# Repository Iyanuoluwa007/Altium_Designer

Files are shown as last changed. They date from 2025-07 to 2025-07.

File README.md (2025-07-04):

# Embedded Control System for an Autonomous Cleaning Robot

This repository documents the design and implementation of the **electronic control system** for an autonomous cleaning robot. It includes detailed PCB and schematic designs created using **Altium Designer**, covering four main subsystems: Power Supply Unit (PSU), USB Control Unit (UCU), Microcontroller Unit (MCU), and Motor Driver Unit (MDU).

## 📌 Project Overview

The objective was to create a robust, modular embedded control system capable of powering and managing key robotic functions such as:

- Obstacle detection and avoidance  
- Motor control and path navigation  
- Wireless communication via ESP32  
- Integration with peripherals like cameras, ultrasonic sensors, and LCDs  

## 🔧 Hardware Components

- **PSU:** Based on LM2596T-5.0 and LM2596T-3.3 for 5V and 3.3V outputs  
- **UCU:** FT232RL-based USB-to-Serial interface  
- **MCU:** ATmega128 microcontroller interfacing with sensors and wireless modules  
- **MDU:** L6205 dual full-bridge motor driver for bidirectional DC motor control  
- **PCB Tool:** Altium Designer (schematic, layout, DRC, and 3D visualization)

## ✅ Features

- Power-efficient voltage regulation with thermal management
- Fault-protected motor driver system
- Multiplexed UART switching for optimized communication
- Altium DRC-verified PCB designs with ground polygon pour
- Modular design enabling system scalability

## 📷 Previews

| Schematic | PCB Layout | 3D Render |
|---|---|---|
| PSU, UCU, MCU, MDU | 2D Altium Layout | Full-board 3D View |

> Note: Visuals available in the `3d_views/` and `outputs/` folders.

## 🔬 Testing & Validation

- **DRC:** No critical violations (Silk-to-solder mask clearance warning only)
- **Thermal Analysis:** Optimized using hatched polygon pour
- **System Integration:** Verified functional with all sensors and modules

## 📡 Future Improvements

- Add heatsinks/fans for thermal management  
- Upgrade to brushless DC motors  
- Include current sensing for real-time diagnostics  
- Add supercapacitor-based backup power

## 📚 References

Key component datasheets and academic papers are cited in the full [project report](./docs/Oke_Iyanuoluwa_Mech_Report.pdf).

## 👥 Author

- **Oke Iyanuoluwa Enoch**

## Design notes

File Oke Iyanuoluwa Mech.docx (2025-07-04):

Design and Implementation of the Embedded Control System for an Autonomous Cleaning Robot

Oke Iyanuoluwa Enoch

Team members: Love Akinrele, Ifeorah Anthony, Revanth Reddy

@00659936

Lecturer: Dr Theo Theodoridis

Module Title: Mechatronics

Programme: MScs. Robotics and Automation

School of CSE, University of Salford, Manchester M5 4WT, UK

i.e.oke@edu.salford.ac.uk

Abstract - This report details the design and implementation of the control system for an autonomous cleaning robot. The project covers the design and development of key electronic subsystems, including a Power Supply Unit (PSU), USB Control Unit (UCU), Micro-Controller Unit (MCU), and Motor Driver Unit (MDU). Using Altium Designer Software for schematic designs and PCB layout were created for each subsystem. The design adheres to professional standards, ensuring efficient operation and integration of sensors and actuators. Performance tests demonstrate the robustness of the system, providing a reliable foundation for further development in robotic cleaning applications.

I. Introduction

The rapid growth in demand for automation in both household and industrial cleaning tasks has significantly advanced robotic technologies. Robots' ability to perform repetitive, labor-intensive tasks autonomously and efficiently has made them indispensable in these environments. This report focuses on the design and implementation of the electronic control system for an embedded cleaning robot, which integrates key components such as motor drivers, sensors, and power management units. These components form the foundation of the robot’s functionality, enabling it to navigate, clean, and avoid obstacles effectively.

The motivation behind this investigation lies in the challenge of developing a cost-effective, reliable, and efficient cleaning robot capable of operating in diverse environments. The growing adoption of smart home and industrial automation solutions inspired this project, as these technologies aim to enhance productivity and streamline routine tasks. The primary objective of this study is to design an electronic control system that optimally manages the robot’s operations, from basic movement and cleaning behaviors to advanced obstacle detection and avoidance.

This investigation is particularly important for advancing the field of embedded robotic systems. Improvements in control systems, such as optimized motor drivers and power management, can significantly enhance the performance, efficiency, and adaptability of autonomous robots. Additionally, the integration of advanced control algorithms into the system contributes to the development of more sophisticated and capable robotic platforms. The system developed in this project lays the groundwork for future innovations in autonomous cleaning robots, providing a scalable solution that can be further refined for broader applications.

Throughout this project, collaborating with students from Pakistan and Nigeria emphasized the significance of fostering an inclusive and supportive environment. Each team member brought a unique cultural, ethnic, and educational perspective, so we prioritized open communication and mutual respect. We actively encouraged the sharing of diverse viewpoints during brainstorming sessions and problem-solving discussions, which enriched our project by providing fresh insights into design challenges.

We recognized the importance of accommodating religious and cultural differences by remaining flexible with meeting times to respect prayer schedules and personal commitments. Additionally, we were mindful of varying educational backgrounds, ensuring that technical concepts were openly discussed so everyone felt supported in understanding and contributing to the project's technical aspects.

By cultivating a culture of respect, inclusion, and cooperation, we enhanced both teamwork and creativity. This inclusive approach allowed us to collaborate harmoniously, providing equal opportunities for every member to contribute. Ultimately, this not only improved the quality of our work but also led to the overall success of the project, showcasing the value of diversity in achieving shared goals.

The remainder of this report is organized as follows. The Literature Review section examines current research and technological advancements related to embedded cleaning robots. The Methods section provides an in-depth description of the electronic subsystems' design, including Power Supply Unit, USB Control Unit, Micro-Controller Unit, and Motor Driver Unit. In the Results section, experimental outcomes and performance evaluations are presented. Finally, the Conclusions section discusses the findings and potential directions for future work.

This report focuses solely on the electronic design aspect of the project, while programming and mechanical design are covered in team members' reports, collectively providing comprehensive documentation of the embedded control system for an autonomous cleaning robot.

II. Literature Review

The growing demand for autonomous cleaning solutions in households and industries has driven research in robotic control systems, sensor integration, and power management. This review explores key technologies in embedded cleaning robots, focusing on control units, motor drivers, and energy systems. It highlights areas for innovation and advancements in control algorithms to enhance performance and reliability.

The author [3] presents the development of a vacuum cleaner robot aimed at automating household cleaning. The robot is designed with an Arduino-based control system, utilizing ultrasonic sensors for navigation and obstacle detection. It features a disk-shaped body, two rear wheels, and a front caster for maneuverability, with rotating sweepers to gather dirt into a vacuum. Powered by lithium-ion batteries, it operates for two hours on a full charge. The study demonstrates the robot’s efficiency in cleaning and navigating, though limitations such as the dustbin size and navigation glitches were noted. Future improvements could involve scaling up the dustbin and enhancing navigation systems for broader applications in home and office environments.

The authors [4] present the development of an autonomous robotic vacuum cleaner designed to save time and reduce effort for users. The system employs multiple sensors, such as infrared (IR) and ultrasonic sensors, for obstacle detection and navigation. A central ARM Cortex M3 controller processes sensor data and controls the robot's movement via permanent magnet DC (PMDC) and servo motors. The vacuum cleaner operates autonomously, utilizing suction to collect dirt. The robot is designed to assist busy individuals, the elderly, and physically challenged users. With future advancements, the robot has potential applications in homes, offices, and other public spaces.

The authors [5] present the development of a smart vacuum cleaner designed to operate autonomously without human intervention. The system integrates an RC car carrying a vacuum cleaner, controlled via an Arduino UNO microcontroller. An ultrasonic sensor detects obstacles, guiding the car to adjust its path based on obstacle distance. A CPU fan provides suction, collecting dust into a detachable container. The cleaner is powered by batteries, making it portable and efficient. The system offers a cost-effective and straightforward design, with potential applications in hazardous environments and daily cleaning tasks. Future improvements may include enhanced dust collection mechanisms and further automation.

The authors [6] present a Bluetooth-based smart vacuum cleaner designed for autonomous cleaning using IoT technology. The system includes a vacuum mounted on a mobile robot chassis equipped with sensors, a microcontroller, and Bluetooth communication. Controlled via a mobile app, the vacuum cleaner can navigate around obstacles and perform tasks remotely. The system uses sensors to detect its environment and an RFID-based positioning system for accurate location tracking. The robot autonomously cleans predefined areas and self-charges when needed. The study demonstrates that the integration of IoT and open-source hardware can facilitate daily household tasks, providing a functional and cost-effective solution for smart cleaning.

The authors [7] designed and implemented a low-cost vacuum cleaner robot controlled via a smartphone, aimed at being accessible to more users. The robot autonomously navigates around obstacles using ultrasonic and infrared sensors while being controllable through a mobile application. It integrates basic cleaning algorithms such as random walk and snake movement to clean efficiently, avoiding walls and cliffs. The study highlights the robot’s ability to provide efficient, low-power cleaning with cost-effective components, demonstrating that affordable robotic solutions for household chores are viable.

The authors [8] present the design and development of a prototype robot vacuum cleaner, using low-cost, off-the-shelf components. The navigation system employs fuzzy logic to enable efficient movement in unknown environments. The hardware includes a Rex-12 Round Robot Base and SRF08 ultrasonic sensors, while the software relies on eLinOS and Simulink for control and navigation. The system was validated using Software-in-the-Loop (SIL) simulations and a virtual prototype to test the navigation algorithm. However, experimental tests revealed the need for improvements in the sensing system to enhance position estimation accuracy.

The authors [9] designed a dual-mode robot vacuum cleaner prototype based on Arduino Uno, which operates in both automatic and manual modes. The robot uses a Sharp GP proximity sensor for obstacle detection and a Bluetooth HC-05 module for smartphone control. In automatic mode, the robot navigates randomly, avoiding obstacles, while in manual mode, users control the robot via a smartphone app. The prototype was tested for suction efficiency and maneuverability, showing limitations in steep slopes and larger debris handling. Further improvements are recommended for enhanced performance.

The authors [10] developed a wireless charging system for robot vacuum cleaners using inductive power transfer (IPT) technology. The system employs curved coils and passive power repeaters to enhance magnetic field coupling, improving charging efficiency despite coil misalignment. The prototype, tested with a 32W power transfer capacity at 100 kHz, demonstrated successful charging under simulated conditions. However, the system showed some limitations in power transfer optimization, suggesting future improvements in coil design and the potential use of active power repeaters for greater efficiency.

The authors [11] developed an Arduino-based smart vacuum cleaner robot, designed to clean autonomously without human intervention. The robot uses an Arduino Uno, ultrasonic sensors for obstacle detection, and motor shields to control movement. Powered by a 12V battery, the vacuum system includes a fan and motor for suction, effectively cleaning hazardous environments. The robot was tested for its obstacle avoidance and cleaning capabilities. While cost-effective and customizable, limitations were noted in efficiency when handling uneven surfaces, and further improvements were suggested for enhanced performance.

The author [12] discusses the design of a vacuum cleaner motor drive inverter using the EPC9176 evaluation board. The inverter uses three EPC23102 eGaN ICs in a three-phase configuration, providing high efficiency and power density. It operates at switching frequencies up to 250 kHz and delivers 18 ARMS with a heatsink. The design incorporates protection functions, current and temperature sensing, and a microcontroller interface. The system is optimized for BLDC motor control, demonstrating reduced torque oscillations, improved efficiency, and better current waveforms for vacuum cleaner applications

The authors [13] designed and analyzed an automatic robotic vacuum cleaner using an Arduino microcontroller and axial fan. The robot uses ultrasonic sensors for obstacle detection and a motor-driven wheel system for movement. Powered by a 12V rechargeable Li-Po battery, it runs for 20-30 minutes on a full charge. Simulation was performed using Coppelia Robotics and ANSYS Fluent to analyze vacuum efficiency. The design is affordable and suitable for Indian markets, with potential applications in households and industries.

The authors [14] designed and fabricated a robotic vacuum cleaner with autonomous functionality using an Arduino Uno and various sensors. The robot features a vacuum system, mopping mechanism, and drying capability, supported by 12V motors for movement. It integrates IR and ultrasonic sensors for obstacle detection and navigation. The control system allows the robot to switch between various cleaning modes and adjust its speed. The study highlights the potential of this cost-effective design for domestic use, especially for elderly or busy individuals.

The authors [15] proposed the integration of Altium Designer software in teaching electronic circuits. The software provides a platform for schematic capture, simulation, and PCB design, allowing students to visualize and analyze circuits effectively. It simplifies debugging and error correction while offering features like fourier analysis, waveform simulation, and cross-probing. The study demonstrates how Altium Designer enhances students' learning experience by reducing manual tasks, improving accuracy, and offering hands-on circuit design, making it an essential tool for both education and research.

The authors [16] developed an autonomous robotic vacuum cleaner that operates in three modes: manual, automatic, and timer-based. The device integrates a NodeMCU microcontroller and ultrasonic sensors for obstacle detection, along with a vacuum and wet mopping mechanism. Controlled via a smartphone app, the robot can clean surfaces by avoiding obstacles and adjusting its path accordingly. It features both vacuuming and wet mopping capabilities for comprehensive cleaning. Testing demonstrated successful obstacle avoidance and efficient cleaning, though the authors suggest further refinement for wider applications.

The authors [17] proposed a cost-effective IoT-based vacuum and mopping robot designed with an Arduino Uno board, ultrasonic and infrared sensors, and Bluetooth control. The robot operates in both automatic and Bluetooth-controlled modes, utilizing a vacuum kit for dust collection and side brushes for efficient cleaning. Ultrasonic sensors detect obstacles, while an L293D motor driver controls the robot's movement. The design aims for maximum cleaning coverage and mobility. Testing showed efficient cleaning and obstacle avoidance, with potential for further enhancements in sensor accuracy and functionality.

The authors [18] developed a robot vacuum cleaner using the Arduino Mega 2560 microcontroller, incorporating ultrasonic sensors for obstacle detection and dust sensors for cleaning. The robot uses four ultrasonic sensors to navigate in cardinal directions and detects dust levels below 0.30 mg/mm³ to activate cleaning. The vacuum operates in forward, backward, and turning movements based on sensor input. The system's performance is displayed on an LCD, with the robot stopping if thicker dust or obstacles are detected. Testing confirmed effective movement and cleaning within the specified parameters.

The authors [19] designed an autonomous vacuum cleaning robot with a focus on cost optimization. The robot features an Arduino Mega 2560 microcontroller, limit switches, infrared sensors, and a DC motor to control movement and obstacle avoidance. A bevel gear system reduces the need for individual motors for each cleaning brush. The robot is designed to vacuum dust and small debris efficiently while navigating obstacles and stairs. With a low manufacturing cost of ₹5,410, the prototype performs well for commercial cleaning but could benefit from additional features such as GPS and automatic charging systems.

The authors [20] developed an intelligent vacuum cleaner that integrates sensor, positioning, and control technologies for autonomous cleaning. The system features an Stc89c52rc microcontroller, infrared sensors for tracking and obstacle avoidance, and ultrasonic sensors for distance detection. The vacuum cleaner can navigate, avoid obstacles, and clean efficiently without manual control. It also includes a motor control circuit for dust collection and a remote control for user interaction. The design emphasizes intelligence, efficiency, and ease of use, marking a significant advancement in household cleaning technology.

The authors [21] designed a smart vacuum cleaner equipped with indoor localization and obstacle detection. The robot uses TurtleBot technology with a SLAM algorithm for simultaneous mapping and localization. It features infrared and ultrasonic sensors for object detection, a motor driver system, and is controlled by an Arduino microcontroller. The vacuum can operate in both manual and autonomous modes. The study emphasizes the use of simulation environments like ROS and Gazebo to optimize path planning and improve cleaning efficiency, showcasing potential applications in homes and commercial spaces.

III. Methods

The intelligent system architecture of the Embedded Cleaning Robot integrates four core functions: rectangular path navigation, target tracking for recharging, obstacle avoidance, and random wandering to explore uncovered areas. Each function is managed by the robot's main control board, consisting of a Power Supply Unit, USB Control Unit, Micro-Controller Unit, and Motor Driver Unit, enabling efficient, adaptive operation in dynamic environments with seamless sensor integration and precise motor control.

Power Supply Unit (PSU)

The Power Supply Unit (PSU) uses two LM2596-based step-down regulators to convert a 12V input into two stable DC outputs:

5V Output: Using the LM2596T-5.0 regulator, this output powers components requiring 5V.

3.3V Output: Using the LM2596T-3.3 regulator, this output powers components requiring 3.3V.

These designs prioritize efficiency, stability, and thermal management, ensuring the proper functioning of embedded systems and other sensitive electronics. Below are the schematic and PCB layout designs for the PSU, prepared using Altium Designer, showing component placement and connections. This setup provides efficient power to the system with minimal ripple, high stability, and low thermal impact.

LM2596T-5.0:

Model Description

The PSU design features the LM2596T-5.0, a fixed-output buck converter that steps down a 12V input to 5V with minimal ripple and noise, supporting up to a 3A load. Operating at a fixed switching frequency of 52 kHz, it ensures compact and efficient filtering while incorporating fault protection mechanisms such as thermal shutdown and overcurrent limits.

Electrical Characteristics

The LM2596T-5.0 offers the following electrical parameters for the PSU:

- Output Voltage: Stable at 5V, with typical tolerances of ±4% across load and line conditions.

- Oscillator Frequency: Fixed at 52 kHz, which maintains switching frequency consistency and improves voltage regulation allowing compact and efficient filter designs.

- Current Limit: 5.8A peak, preventing excessive current flow and protecting against faults.

- Input Voltage Range: Operates with a wide range of input voltages.

Thermal Management and Power Dissipation

- Thermal Shutdown: Built-in thermal shutdown ensures safe operation by automatically disabling the IC if temperatures exceed safe limits.

- Thermal Resistance: With θJA at 65°C/W (TO-220 package) and junction temperature max at 125°C, the power dissipation under normal operation is within safe ranges with limited or no additional heat sink requirement.

- Power Dissipation Equation: Power dissipation (PD) can be calculated using:

PD=(VIN x IQ)+(VO/VIN) X ILOAD x VSAT

where VIN is 12V, IQ (quiescent current) is 5 mA, VO is 5V, and VSAT is approximately 1.4V for the LM2596T-5.0.

Performance Under Load and Temperature Tolerances

Graphs from the datasheet show:

- Efficiency vs Load Current: At 3A, efficiency reaches around 77%.

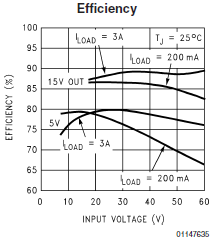
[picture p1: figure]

- Ripple Voltage: The output ripple can be managed with the 1000 µF output capacitor, achieving smooth operation and low noise at approximately 1% of the output voltage.

## ~~I~~mplementation Design

The LM2596T-5.0 PSU is designed to efficiently convert a 12V DC input to a stable 5V DC output, ideal for powering embedded systems.

i. Input Power and Filtering: The 12V input, provided through a power jack and SPST switch, is stabilized by capacitors (100 µF and 10 nF) to filter high-frequency noise, reducing oscillations for smooth regulator operation.

ii. Voltage Regulator Module: The LM2596T-5.0 regulator steps down the input to a steady 5V, chosen for its efficiency and ability to manage higher input voltages with minimal power loss.

iii. Inductor (100 µH): The 100 µH inductor supports energy storage and smooths the current, minimizing ripple crucial for stable applications.

iv. Output Capacitor (1000 µF): Positioned as the primary output filter, the 1000 µF capacitor smooths residual ripple, enhancing stability. Its voltage rating is selected above 5V to ensure durability against minor surges.

v. Catch Diode (1N5822): This Schottky diode, with fast switching and low forward voltage drop, prevents current backflow, protecting the circuit during off cycles.

vi. Indicator LED and Resistor: An LED and 330-ohm resistor signal the output status, providing a simple verification tool.

vii. Output Connector: A 2-pin connector offers easy 5V access for external devices, creating a reliable, efficient PSU for systems requiring stable power.

LM2596T-3.3:

Model Description

The LM2596T-3.3 regulator steps down a 12V input to a stable 3.3V output. It supports up to 3A load and includes the same thermal and overcurrent protection as the LM2596T-5.0.

Electrical Characteristics

- Output Voltage: Nominal output is 3.3V, with ±4% tolerance.
- Oscillator Frequency: Fixed at 52 kHz, enabling efficient filtering.
- Current Limit: Peak current limit of 5.8A.
- Input Voltage Range: Accepts input voltages of 12V in this PSU design.

Thermal Management and Power Dissipation

- Thermal Shutdown: Automatically disables the IC in case of overheating.
- Thermal Resistance: θJA: 65°C/W for the TO-220 package. Maximum junction temperature: 125°C.
- Power Dissipation: Calculated similarly to LM2596T-5.0, using:

PD=(VIN x IQ)+(VO/VIN) X ILOAD x VSAT

where VIN is 12V, IQ (quiescent current) is 5 mA, VO is 3.3V, and VSAT is approximately ~1.4V.

Performance Under Load and Ripple Voltage

- Efficiency: Efficiency can reach 78% under typical load conditions.
- Ripple Voltage: Ripple is minimized using a 330 µF output capacitor, maintaining noise at around 1% of output voltage.

Implementation Design

The LM2596T-3.3 PSU is designed to efficiently convert a 12V DC input to a stable 3.3V DC output, ideal for powering embedded systems.

i. Input Power and Filtering: The 12V input is filtered using a 330 µF capacitor to suppress high-frequency noise.

ii. Voltage Regulator Module: The LM2596T-3.3 steps down 12V to 3.3V, ensuring stability and low noise.

iii. Inductor: A 33 µH inductor smooths current flow, reducing ripple.

iv. Output Capacitor: A 330 µF capacitor filters the output voltage, ensuring a stable 3.3V output.

v. Catch Diode: A 1N5822 Schottky diode prevents reverse current flow.

vi. Indicator LED and Resistor: An LED and 330-ohm resistor signal the presence of the 3.3V output.

vii. Output Connector: A 2-pin connector provides access to the regulated 3.3V output.

Below is the Schematic and PCB diagram showing the connection of the Power Supply Unit (PSU):

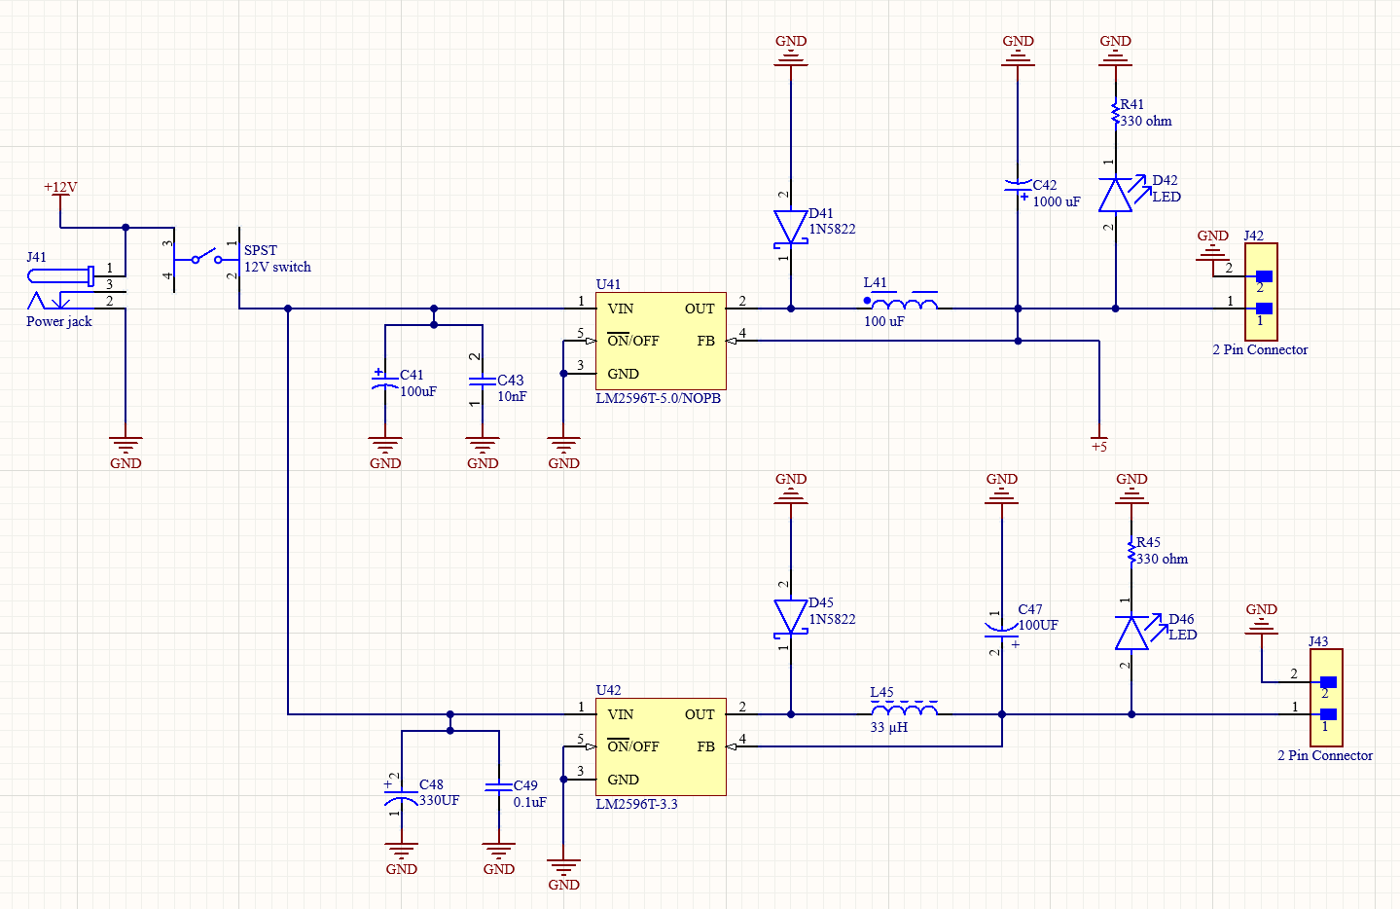
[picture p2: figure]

Fig. 1a The schematic diagram of the PSU (Power Supply Unit

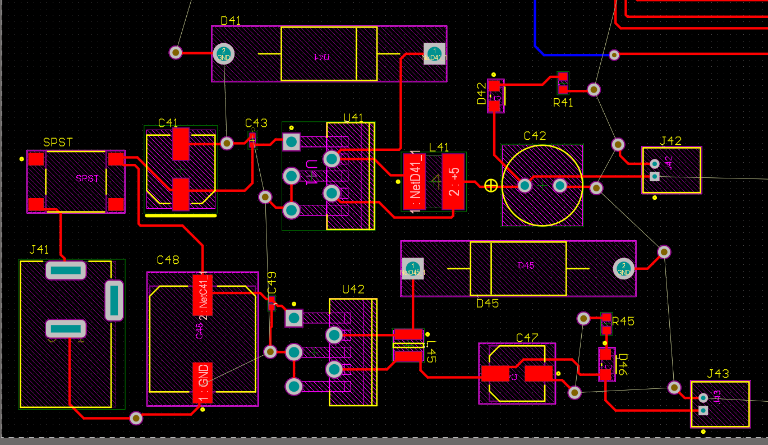
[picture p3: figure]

Fig 1b. The Printed Circuit Board (PCB) of the PSU (Power Supply Unit

USB Control Unit (UCU)

The UCU is the USB interface used to establish bidirectional communication with the PC over a USB-to-Serial protocol. Using the FT232RL functions as the USB-to-serial UART interface. The design can include the following essential elements:

- VCCIO: Configured based on the voltage requirement (1.8V to 5.25V). This can be set to interface with other components in the circuit.

- USB Data Lines (USBDP and USBDM): Connected to the USB connector with internal pull-up resistors for proper USB 2.0 full-speed communication.

- CBUS Pins: Configurable GPIO pins (CBUS0-4) set in the EEPROM to control additional functions like LEDs for data indication or to manage power settings via PWREN.

FT232RL Configuration and Analysis

The FT232RL integrates critical functions needed for USB communication and UART interfacing:

Electrical Characteristics:

- Operating Voltage: 3.3V to 5V nominal operating voltage; the internal LDO provides a regulated 3.3V output.

- Current Requirements: Operating at approximately 15mA in normal mode and 70µA in USB suspend mode, supporting low-power applications.

Thermal Characteristics:

- Suitable for a temperature range of -40°C to 85°C, making it versatile for embedded applications.

- The IC includes an internal power-on-reset (POR) and a 3.3V LDO, reducing the need for additional thermal management components like heat sinks for moderate power applications.

Performance Specifications:

- Data Rate: Capable of up to 3 Mbaud for serial communication, with a baud rate generator allowing non-standard rates via internal prescaler adjustments.

- Integrated EEPROM: Stores device descriptors, VID, PID, and custom configurations for the CBUS pins(FT232R).

FT232RL Key Functional:

- USB Protocol Engine: Manages USB control endpoint data flow and low-level protocol requests from the host.

- UART Controller: Converts data between USB and UART formats, with support for signal inversion and a configurable drive strength to interface efficiently with various UART levels.

The baud rate equation for the FT232RL is calculated using:

Baud Rate = 3,000,000 / n + x

where n is an integer between 2 to 16,384 and x a fractional divisor (0, 0.125, etc.), giving a wide range of achievable baud rates from 183.1 baud to 3,000,000 baud.

## Implementation Design

The FT232RL chip serves as the primary USB interface in the USB Control Unit (UCU), facilitating bidirectional data communication between a PC and an embedded system by converting USB signals to UART protocol.

1. USB Data Lines (USBDP, USBDM): The differential data lines, D+ (USBDP) and D- (USBDM), are directly connected to the USB port. These lines manage data transmission to and from the PC, enabling communication via USB.

2. Power Supply (VCCIO): VCCIO pin supplies the logic level for UART and CBUS pins, configured to either 3.3V or 5V depending on the MCU’s interfacing requirements. This ensures the chip communicates at the proper voltage level.

3. UART Interface Pins (TXD, RXD): The TXD (Transmit) and RXD (Receive) pins handle serial data exchange with the ATmega128-16AU, providing full-duplex communication capability.

4. CBUS I/O Pins (CBUS0-4): Configurable through the integrated EEPROM, CBUS pins can be assigned to auxiliary functions like TX and RX LED indicators or used as general-purpose I/O pins.

5. EEPROM: The FT232RL’s internal EEPROM holds USB descriptors (e.g., Vendor ID and Product ID) and the configuration settings for CBUS pins, allowing easy customization and integration with USB host systems.

6. PCB Layout and Design Considerations:

- USB and Power Routing: The D+ and D- lines are routed as differential pairs with controlled impedance to maintain signal integrity. Power traces are designed short and wide to handle current demands efficiently.

- LED Indicator Circuit: LEDs, each with a 330-ohm resistor (R33 for RX, R34 for TX), indicate the operational status of data transmission, providing a visual check for communication activity.

- The VBUS signal is directly connected to 2OE (Pin 4) of the multiplexer (Z2).

7. Connector Configuration:

- USB Connector: The USB-B connector interfaces with the PC, allowing standard USB connectivity.

Below is the Schematic and PCB diagram showing the connection of the USB Control Unit (UCU):

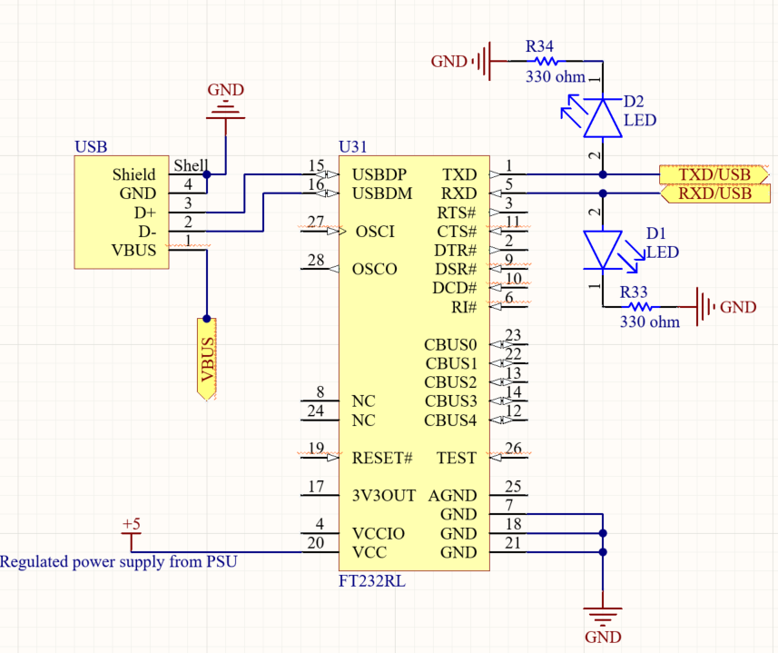
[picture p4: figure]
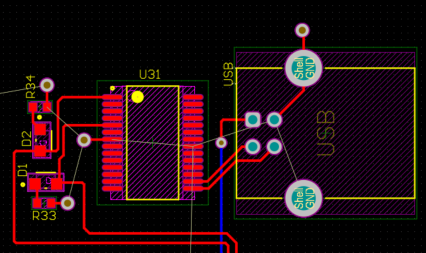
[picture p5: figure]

Fig. 2a The schematic diagram of the USB Control Unit (UCU)

Fig. 2b The Printed Circuit Board (PCB) of the USB Control Unit (UCU)

Motor Driver Unit (MDU)

The Motor Driver Unit (MDU) uses the L6205 full-bridge motor driver IC, designed for driving DC motors efficiently while ensuring reliability and robust protection. The L6205 supports a dual full-bridge configuration, making it ideal for driving two independent DC motors. With built-in features like overcurrent protection, thermal shutdown, and undervoltage lockout, the MDU ensures safe and stable operation for embedded motor control systems.

Features of the MDU

- Dual Full-Bridge Motor Driver: Supports two independent motors with separate control signals.
- High Voltage and Current Capability:

i. Supply Voltage (VSA/VSB): Up to 52V.

ii. Output Current (IOUT): 2.8A RMS per channel.

- Integrated Protection Mechanisms:

i. Overcurrent Protection: Prevents damage due to motor stall or excessive load.

ii. Thermal Shutdown: Disables operation when IC temperature exceeds the threshold.

iii. Undervoltage Lockout: Ensures the motor operates only within safe voltage levels.

- Low RDS(on): MOSFET switches integrated into the driver reduce heat dissipation.

Circuit Implementation and Connections

The MDU design consists of two identical motor driver circuits, each built around an L6205 IC. The following sections describe the critical components and their functions:

1. Input Power Supply

i. Voltage Source (VS): The motors are powered by a 12V DC input.

ii. Capacitors (C13, C14, C15, C16):

- 100 µF capacitors filter noise and smooth voltage input.

- 220 nF bootstrap capacitor (CBOOT): Ensures high-side MOSFETs can switch correctly.

2. Control and Logic Inputs

i. Enable Pins (EN_A, EN_B): Used to enable or disable each motor. Controlled by microcontroller logic.

ii. Input Pins (IN1, IN2): Determine the motor's rotation direction based on logic levels:

- IN1 High, IN2 Low: Forward rotation.

- IN1 Low, IN2 High: Reverse rotation.

- Both Low: Motor brakes.

iii. Resistors (M_RENA,B and M_CENA,B): Pull-up and pull-down resistors stabilize input signals, minimizing noise.

3. Output Stage

i. The driver outputs (OUT1a, OUT2a, OUT1b, OUT2b) connect to the motor terminals via a 2-pin connector (J4, J5).

ii. Each channel provides a full-bridge output, allowing bidirectional control of motors.

4. Bootstrap Circuit

Diodes (1N4148): Fast recovery diodes ensure proper charging of the bootstrap capacitors during switching cycles.

5. Sensing and Protection

Sense Resistors (SENSE_A, SENSE_B): Connect to the ground for overcurrent sensing. These are crucial for triggering protective mechanisms within the IC.

Thermal Management and Power Dissipation

i. Thermal Shutdown: The L6205 has an internal thermal sensor that disables operation when the junction temperature exceeds safe limits.

ii. Power Dissipation (PD): Power dissipation for each channel can be calculated using:

PD = I² × RDS (on) × Duty Cycle

With the low RDS (on) value of the L6205, power loss is minimal, enhancing efficiency and reducing the need for large heat sinks.

Performance Characteristics

- Efficiency: The low RDS(on) and optimized switching characteristics result in high efficiency across various loads.
- Current Control: Peak current control prevents overheating or motor damage during stall conditions.
- Motor Speed Control: Achieved through Pulse Width Modulation (PWM) applied to the enable pins, allowing smooth speed variations.

Implementation Benefits

The MDU, designed with the L6205 IC, provides the following advantages:

i. Compact Design: Integration of MOSFETs and protection features reduces the need for external components.
ii. High Reliability: Built-in protections ensure long-term stability, even under demanding conditions.
iii. Easy Integration: Compatibility with standard microcontrollers simplifies control logic implementation.

Below is the Schematic and PCB diagram showing the connection of the Motor Driver Unit (MDU):

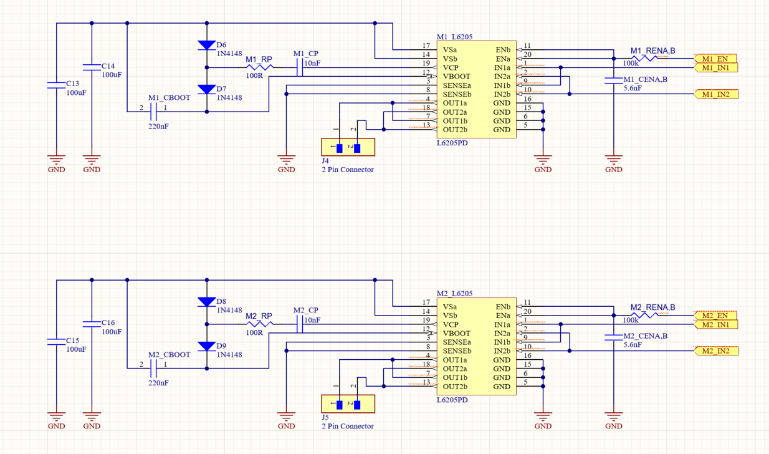
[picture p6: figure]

Fig. 3a The schematic diagram of the Motor Driver Unit (MDU)

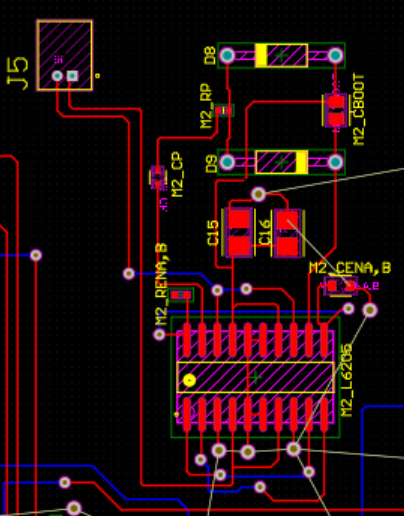
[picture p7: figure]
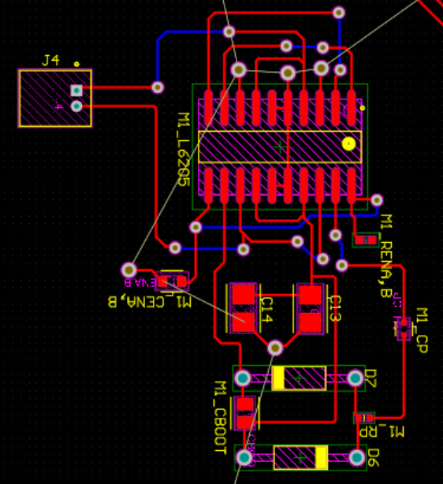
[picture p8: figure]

Fig. 3b The Printed Circuit Board (PCB) of the Motor Driver Unit (MDU)

Microcontroller Unit (MCU)

Micro-Controller Unit (MCU): The MCU is based on the ATmega128, a versatile and widely-used microcontroller from Atmel’s AVR family, known for its high performance and efficient power consumption. It operates on the Harvard architecture with a RISC-based instruction set, enabling efficient execution of embedded applications.

- Core Functionality: The ATmega128 serves as the central processing unit for the system, executing the programmed instructions to control connected sensors, peripherals, and communication modules.

- Integration with Peripherals: As evident in the provided schematic, the MCU interfaces with various components such as Ultrasonic sensors (CON1), a RPLidar (CON2), a Camera (CON3), an I2C LCD (CON4), and an ADC (CON5). These connections highlight the MCU's ability to manage multiple inputs and outputs effectively.

Key Features of the ATmega128 in This Design

1. High Pin Count and I/O Flexibility:

The ATmega128 features 53 programmable I/O lines, enabling connectivity with a wide range of devices. For example, in the schematic:

- PORTB, PORTC, and PORTD are used for communication with peripherals like the ultrasonic sensor and camera module.

- PORTF is leveraged for ADC operations, allowing analog signals to be processed digitally.

2. Communication Protocols:

The microcontroller supports several communication protocols, such as SPI, I2C, and USART:

i. SPI communication is used for high-speed data exchange such as with the OV2640 camera module.

ii. I2C is used to connect the I2C-based LCD for efficient data transfer with minimal pin usage.

iii. USART facilitates communication with the ESP32-WROOM-32D module for wireless data exchange.

To ensure proper functionality, careful pin management has been implemented. For instance, the PB1/SCK line is shared between the ISP header and the camera module, with programming only possible when the camera is inactive.

3. Analog and Digital Conversions:

Equipped with a 10-bit ADC (on PORTF pins), the ATmega128 can convert analog signals from sensors into digital data for processing.

4. Timers and PWM:

The ATmega128 includes four timers (8-bit and 16-bit) to handle tasks like event counting, signal generation, and control. PWM outputs are also used for applications requiring precise modulation, such as motor control.

5. Programming and Debugging:

An In-System Programming (ISP) header is connected to PB1-SCK, PB2-MISO, PB3-MOSI, and the RESET pin, enabling programming and debugging of the microcontroller during development.

6. Crystal Oscillator:

The design includes a 16 MHz crystal oscillator with 18 pF capacitors (C5 and C6), providing the clock signal necessary for stable MCU operation.

Detailed Component Connections

1.Power Supply Connections:

- The ATmega128 is powered by a stable 5V supply regulated by the LM2596T-5.0.

- AVCC powers the ADC module, and AREF sets the reference voltage for analog-to-digital conversions.

- Decoupling capacitors stabilize the power supply and filter noise for reliable operation.

2. Clock Signal:

A 16 MHz external crystal oscillator provides the clock source for the MCU, ensuring precise timing and synchronization of internal processes.

3. Peripheral Connections:

- Ultrasonic Sensor (CON1):

Connected to PORTD (PD0-PD7) for transmitting trigger signals and receiving echo pulses for distance measurement.

- Camera Module (CON3):

The OV2640 camera module is linked to PORTC (PC0-PC7) for transferring image data to the MCU. SPI is used for communication.

- LCD Module (CON4):

An I2C-based LCD is connected via SCL and SDA pins on PORTC, enabling simple and efficient data display.

- ADC Inputs (CON5):

Analog sensors are connected to PORTF (PF0-PF7) for conversion of analog signals to digital data.

4. Wireless Communication Module (ESP32-WROOM-32D):

The MCU communicates with the ESP32 module via the USART interface on PD0 (TXD) and PD1 (RXD), enabling wireless communication over Wi-Fi.

5. Multiplexer:

The design utilizes two multiplexers (Z1 and Z2) for UART switching on the ATmega128.

Z1 connects CON2 (RPLidar) and the ISP to UART1 (PD2/PD3), controlled by the RESET signal. When RESET is HIGH, the ISP connects to UART1; when LOW, RPLidar is active.

Z2 handles UART0 (PE0/PE1), switching between the ESP32 and USB (FT232RL), controlled by the USB’s VBUS signal. When VBUS is HIGH, USB is active; when LOW, the ESP32 is connected. Pull-down resistors ensure stable signal transitions. This configuration enables automatic peripheral switching, optimizing UART usage without manual intervention.

6. ISP Programming Header (CON6):

Provides access to SPI pins (PB1-SCK, PB2-MISO, PB3-MOSI) and the RESET line for programming and debugging.

7. Status Indicator:

A status LED is connected to one of the I/O pins through a resistor, offering visual feedback about the system's operational status.

Below is the Schematic and PCB diagram showing the connection of the Motor Driver Unit (MDU):

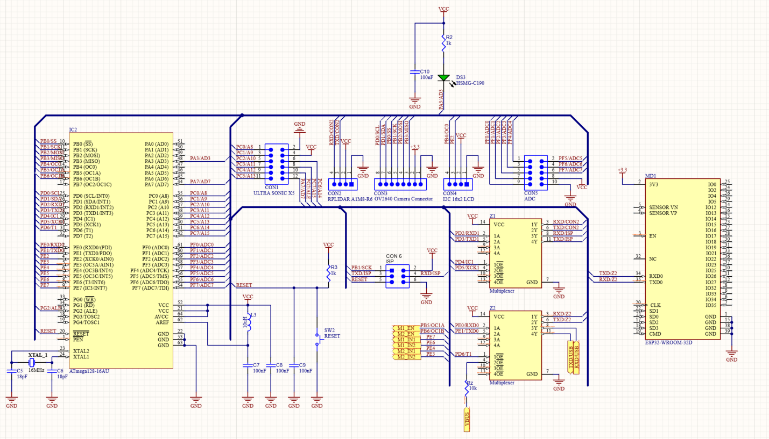
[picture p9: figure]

Fig. 4a The schematic diagram of the Microcontroller Unit (MCU)

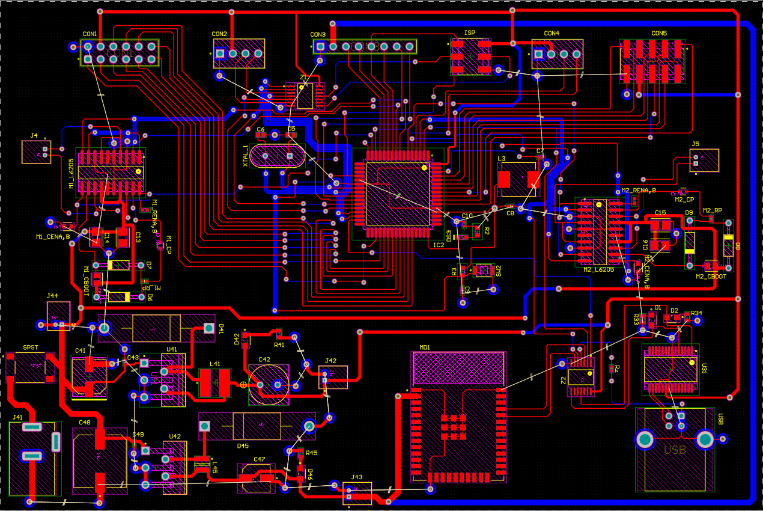
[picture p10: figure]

Fig. 4b The Printed Circuit Board (PCB) of the whole connection to the Microcontroller Unit (MCU)

IV. Results/ Experiments:

This section presents the outcomes and insights derived from the design and implementation of the embedded control system for an autonomous cleaning robot. Utilizing Altium Designer’s Design Rule Check (DRC), the schematic and PCB designs for critical subsystems were meticulously developed and rigorously validated. These results are supported by detailed analyses, 3D renderings, and rule-checking to ensure compliance with professional and industry standards.

The DRC was performed based on the following rule categories:

- Electrical
- Routing
- Surface-Mount Technology (SMT)
- Manufacturing
- High-Speed Design
- Placement

Upon executing the DRC, the Verification Report indicated that all circuit connections were correctly established with zero warnings. The only rule violation identified was related to the Silk to Solder Mask clearance.

The Silk to Solder Mask rule pertains to the required spacing between the silkscreen layer and the solder mask layer on the PCB. The identified violation occurred because the clearance did not meet the 10-mil threshold between the silkscreen and pad areas. This issue arises from the specific components and their placement on the PCB, as their designs do not fully conform to Altium’s default design rules. However, the violation does not compromise the general electrical functionality of the circuit and can therefore be safely disregarded in this context. The Altium Designer Design Rule Verification Report can be found in the link in the Appendices section below.

After performing the DRC, the PCB was properly grounded using the Polygon Pour. The Polygon Pour is referred to as the large area on a printed circuit board (PCB) that is filled with copper. It is often used for grounding, power distribution, or thermal management.

The polygon pours are typically categorized into: Solid and Hatched.

Solid Pour: A solid pour fills the entire defined area with a continuous layer of copper.

Hatched pour: It uses a grid or mesh-like pattern of copper to fill the area, leaving spaces between the copper lines.

In this design, a hatched polygon pour is applied to the bottom layer to connect all components to the ground (GND) net. The hatched pour effectively serves two critical functions:

- Heat Dissipation: The hatched pattern aids in spreading heat generated by components, minimizing the risk of overheating.

- Cost Efficiency: By reducing the amount of copper used compared to a solid pour, the design maintains cost-effectiveness while fulfilling thermal and grounding requirements.

The hatched pour ensures mechanical flexibility, making it suitable for applications where stress and bending may occur. This approach reflects a balanced consideration of performance, cost, and reliability.

Below show the full PCB circuit below:

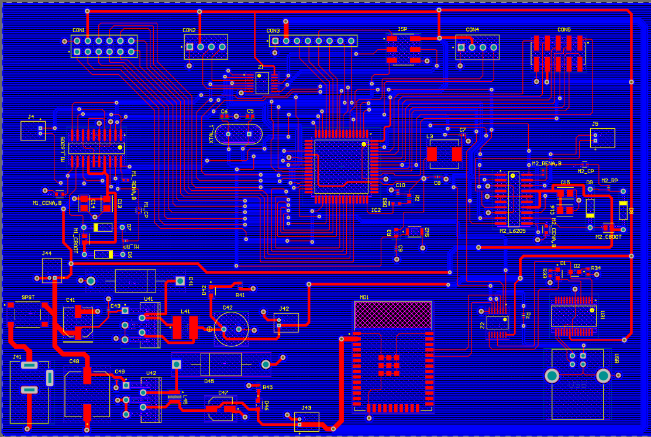
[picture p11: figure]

Fig. 5a 2d PCB Layout mode

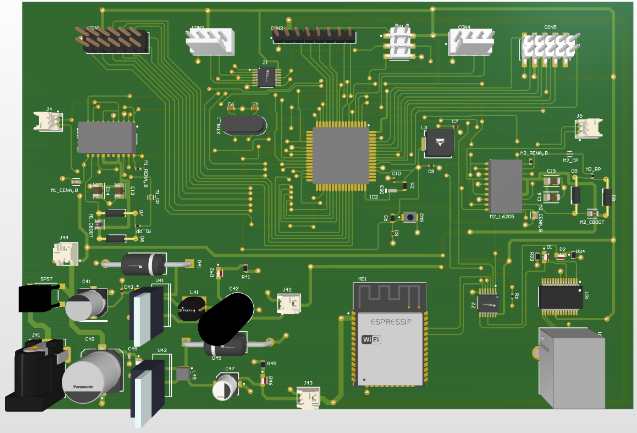
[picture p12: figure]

Fig. 5b 3d PCB Layout mode

V. Conclusions

This project successfully developed a robust electronic control system for an autonomous cleaning robot, integrating a Power Supply Unit (PSU), USB Control Unit (UCU), Microcontroller Unit (MCU), and Motor Driver Unit (MDU). This design adheres to professional and industry standards using Altium Designer for schematic and PCB layout development. The key results highlight:

- Efficient Power Management: The PSU efficiently converts a 12V input to stable 5V and 3.3V outputs, ensuring minimal ripple and optimized thermal management.
- Reliable Control System: The MCU based architecture effectively will manage the robot's cleaning functions, including navigation, obstacle avoidance, and recharging.
- Motor Driver Optimization: The MDU, based on the L6205 IC, provides smooth, bidirectional motor control with integrated overcurrent and thermal protection.
- Seamless Communication: The UCU's USB-to-Serial interface facilitates efficient data exchange between the robot and external systems.

The experimental results validated the functionality of these subsystems, ensuring seamless integration for effective robot operation.

Contributions

The design introduces several innovations that enhance functionality and efficiency.

- Power Management Optimization: The PSU uses a hatched polygon pour for grounding, providing improved heat dissipation and cost-effective thermal management.

- Enhanced Motor Control: The L6205 IC optimizes motor driver performance, ensuring smooth, reliable operations under various conditions.

- Integration of Multiplexers: The multiplexers (Z1, Z2) dynamically manage UART interfaces, allowing seamless switching between devices like the ESP32, USB, and RPLidar. This reduces hardware complexity, simplifies microcontroller pin allocation, and enables simultaneous multi-device communication without manual reconfiguration.

- ESP32 for Wireless Connectivity: The ESP32 module facilitates remote operation and real-time monitoring via Wi-Fi. It gives room for support of IoT functionalities such as scheduling, cloud data storage, and voice assistant integration, offering a powerful, cost-effective connectivity solution.

These innovations emphasize modularity, adaptability, and efficiency, setting a new standard for robotic cleaning system design and enhancing user convenience.

Future Developments

To enhance the electronic control system of the autonomous cleaning robot, several advancements are proposed:

- Heat Dissipation: Integrating a small, energy-efficient cooling fan or heat sinks on the PSU and Motor Driver Unit will mitigate heat buildup, ensuring consistent thermal performance during prolonged use.

- Power Management: Adaptive power management, including dynamic voltage scaling, can optimize energy usage based on workload, while a backup power mechanism (e.g., supercapacitor) ensures reliability during power transitions.

- Motor Control: Adding current-sensing circuits for dynamic load adjustments and upgrading to brushless DC motors will increase energy efficiency and durability.

- Diagnostics: Real-time power monitoring and status indicators for key subsystems will simplify maintenance and improve user feedback.

These developments aim to enhance reliability, energy efficiency, and scalability for future applications.

Overall Impact

The project demonstrates how an efficient, scalable control system can enhance the functionality and reliability of autonomous cleaning robots, contributing significantly to the field of household and industrial automation.

References

[1] Wikipedia, "Robotic vacuum cleaner," Wikipedia, the free encyclopedia. https://en.wikipedia.org/wiki/Robotic_vacuum_cleaner (accessed Oct. 30, 2024).
[2] My Project Circuits, "Design and construction of a microcontroller-based robot vacuum floor cleaner," My Project Circuits, https://www.myprojectcircuits.com/materials/design-and-construction-of-a-microcontroller-based-robot-vacuum-floor-cleaner/ (accessed Oct. 30, 2024).
[3] Asafa, T. B., Afonja, T. M., Olaniyan, E. A., & Alade, H. O. (2018). Development of a vacuum cleaner robot. Alexandria Engineering Journal, 57(4), 2911–2920. https://doi.org/10.1016/j.aej.2018.07.005
[4] Sagar, P., Kumari, A., Sanyal, V., Choudhary, R., & Diwan, A. (2016). A Review Paper on Autonomous Robotic Vacuum Cleaner, 4(ISSN-2347-4890).
[5] M, M., T S, V., V, B., Rao, S., & P S, G. (2021). Smart vacuum cleaner. Global Transitions Proceedings, 2(2), 553–558. https://doi.org/10.1016/j.gltp.2021.08.051
[6] Güllü, A., & Çağlar, M. (2019). Bluetooth Based Smart Vacuum Design and Implementation. Bilge International Journal of Science and Technology Research, ISSN: 2651-401X. https://doi.org/10.30516/bilgesci.489785.
[7] Eren, A., & Doğan, H. (2022). Design and implementation of a cost effective vacuum cleaner robot. Turkish Journal of Engineering, 6(2), 166–177. https://doi.org/10.31127/tuje.830282
[8] Design of a Prototype Robot Vacuum Cleaner - From Virtual Prototyping to Real Development. (2006). Proceedings of the Third International Conference on Informatics in Control, Automation and Robotics, 461–468. https://doi.org/10.5220/0001201004610468
[9] Rahayu, E. S., Mardiono, & Azis, D. A. (2020). Design of vacuum cleaner dual mode robot prototype based on arduino uno with bluetooth and smartphone communication. 6.
[10] Li, A., Kacprzak, D., & Hu, A. P. (2022). Wireless Charger Design of Robot Vacuum Cleaners with Power Repeaters for High Compatibility. Journal of Electromagnetic Analysis and Applications, 14(05), 47–64. https://doi.org/10.4236/jemaa.2022.145005
[11] Kumar, K. S., Pavan, M., Karthikeyan, N. K., Lokesh, P. S. V., Sasidhar, K., & Haritha, T. (2023). Arduino Based Smart Vacuum Cleaner Robot. International Journal for Research in Applied Science and Engineering Technology, 11(3), 416–424. https://doi.org/10.22214/ijraset.2023.49430
[12] eGaN® TECHNOLOGY. (n.d.). How to Design a Vacuum Cleaner Motor Drive Inverter Using EPC9176 Evaluation Boards.
[13] Harish Bala, S., Prajith, K., Siddharth, B., & Prashanth, B. (2020). Design and Analysis of Automatic Robotic Vacuum Cleaner. International Journal of Advanced Research in Engineering and Technology (IJARET), 11(11), 728–736. https://doi.org/10.34218/IJARET.11.11.2020.069
[14] Kumar, P., Rajpurohit, P., Krishna, H., & Chauhan, S. (2020). Design And Fabrication of Robotic Vacuum Cleaner. 8(ISSN: 2320-28820), 3436.
[15] Beltran, A., Hiwatig, C., Laguna-Agustin, J., & Villanueva, M. (2014). Teaching Electronic Circuits Using Altium Designer Teaching Electronic Circuits Using Altium Designer.
[16] Patil, S., Yelmar, S., Yedekar, S., Mhatre, S., & Pawashe, V. (2021). Autonomous Robotic Vacuum Cleaner Autonomous Robotic Vacuum Cleaner. International Research Journal of Innovations in Engineering and Technology (IRJIET), 5(4), 142–146. https://doi.org/10.47001/IRJIET/2021.504021
[17] Sridhar, S., Himabindu, R., Kumar, P., & Vasu, R. (2018). Design of IOT Based Vacuum Cleaning and Mopping Robot. 5.
[18] Rapa, C. I., Dephtios, E., Mariangga, C., & Patiung, N. (2022). A Design And Build A Robot Vacuum Cleaner. Journal of Physics: Conference Series, 2394(1), 012024. https://doi.org/10.1088/1742-6596/2394/1/012024
[19] Modi, J., & Siddhpuriya, N. (2021). Manufacturing of Autonomous Vacuum Cleaning Robot with Optimum Cost Manufacturing of Autonomous Vacuum Cleaning Robot with Optimum Cost. International Journal of Advance Research in Engineering, 8(6), 2394–2444.
[20] Liu, Y., Rong, X., & Bu, S. (n.d.). Design of Intelligent Vacuum Cleaner.
[21] Toprak, J., & Kamiloglu, A. (n.d.). Design of a Smart Vacuum Cleaner with Indoor Localization.
[22] Texas Instruments, "LM2596T-5.0/LM2596T-5.0HV Series SIMPLE SWITCHER® 3A Step-Down Voltage Regulator," Rev. B, Aug. 2004. Available: https://www.ti.com
[23] Future Technology Devices International Ltd., "FT232R USB UART IC Datasheet," Version 2.10, Document No. FT_000053, Jan. 2010. Available: https://www.ftdichip.com
[24] Atmel Corporation, "ATmega128/L Datasheet: 8-bit Atmel Microcontroller with 128KBytes In-System Programmable Flash," Rev. 2467X–AVR–06/11, June 2011.
[25] STMicroelectronics, “L6205 DMOS Dual Full Bridge Driver”, Sept. 2003.
[26] Texas Instruments, LM2596 SIMPLE SWITCHER® Power Converter 150-kHz 3-A Step-Down Voltage Regulator Datasheet, Rev. G, SNVS124G, Mar. 2023. Available: https://www.ti.com/product/LM2596
[27] Bergman, J., & Lind, J. (2019). Robot Vacuum cleaner.

Appendices

Mechatronics Files: Mechatronics (https://testlivesalfordac-my.sharepoint.com/:f:/r/personal/i_e_oke_edu_salford_ac_uk/Documents/Mechatronics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)
